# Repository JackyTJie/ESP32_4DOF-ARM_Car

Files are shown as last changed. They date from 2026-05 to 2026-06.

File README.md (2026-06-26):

# 第 16 届上海交通大学"黎明杯"新生机械创意大赛
> 主题：工道肇始，百卅同途 | 队名: Blitz
> 比赛结果：**十六强** **最佳设计奖**

<p align="center">
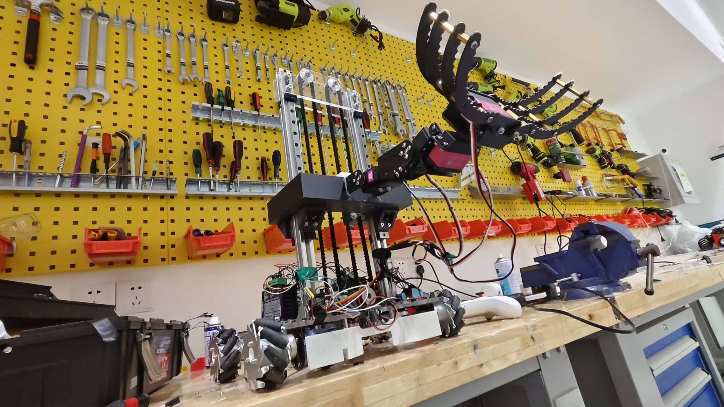
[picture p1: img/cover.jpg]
Cover
  <br/>
  <em>比赛用麦卡纳姆轮全向移动机器人总览</em>
</p>

<p align="center">
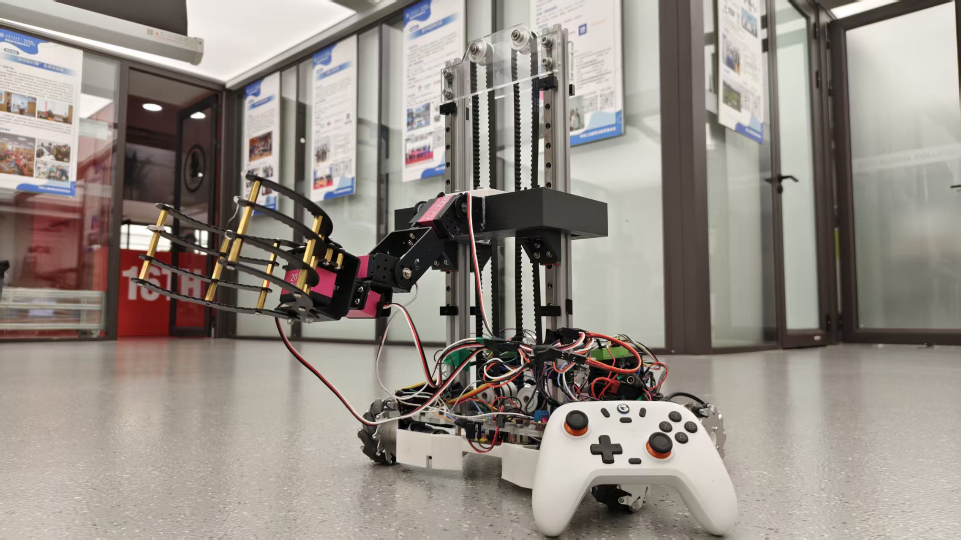
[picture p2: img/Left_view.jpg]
Left View
  
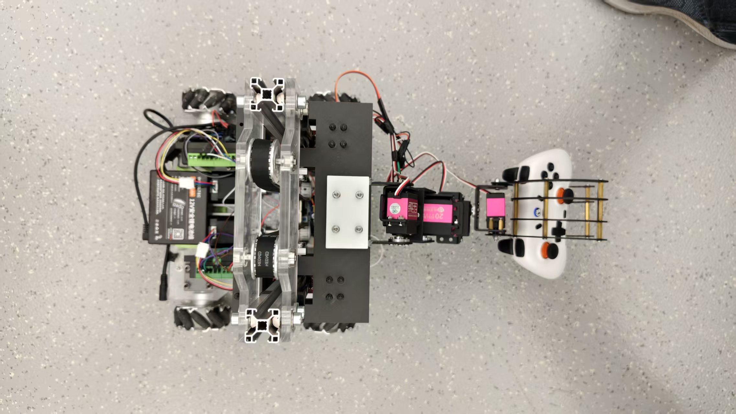
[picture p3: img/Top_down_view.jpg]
Top Down View
  <br/>
  <em>左视图 · 俯视图</em>
</p>

---

## 比赛信息

### 机器人规格限制 (Section 6.1)
| 参数 | 限制 | 当前状态 |
|---|---|---|
| 底盘尺寸 | ≤350×350mm | 符合 |
| 起始尺寸 | ≤450×450×650mm | 符合 |
| 最大展开 | ≤550×550×900mm | 符合 |
| 总重量 | ≤15kg | 符合 |
| 电池电压 | ≤13.2V | 符合(11.1V) |
| 行走电机 | ≤4 个 | 符合(4个MG513) |
| 任务电机 | 不限 | 已配置舵机+步进电机 |

---

## 项目概述
本项目是为第 16 届上海交通大学新生机械创意大赛设计的**麦卡纳姆轮全向移动机器人**。
已完成**Xbox蓝牙手柄控制、MPU6050智能坡道自动驻车、4路舵机机械臂控制、步进电机升降、电池低压保护、编码器速度滤波**全套核心功能，完全满足初赛/决赛关卡需求。

### 比赛关卡与功能完成度
| 关卡 | 任务描述 | 所需机构 | 完成状态 |
|---|---|---|---|
| 1. 奠基之路 | 搬运泡沫块填坑并上坡 | 底盘/推铲/坡道驻车 | **已完成** |
| 2. 权衡定鼎 | 搬运物块到300mm高台 | 机械臂/升降 |**已完成** |
| 3. 重枢巧径 | 操纵配重系统 | 挂钩/推杆 | **已完成** |
| 4. 参数扰行 | 从墙面取障碍物并布置 | 机械臂/夹爪 | **已完成** |
| 5. 同途归一 | 收集拼图并嵌入拼图板 | 机械臂/精密夹爪 | **已完成** |

### 核心功能
-  麦卡纳姆轮全向移动（前后/平移/旋转/混合）
-  **MPU6050六轴传感器·智能坡道自动驻车**（倾角>12°+摇杆回中自动锁轮）
-  Xbox Series X/S 蓝牙无线控制
-  4路舵机精准控制+一键复位
-  步进电机升降加减速控制
-  电池低压告警+临界电压强制停机
-  编码器速度采集+三阶滑动滤波
-  非线性速度曲线，操控更细腻

---

## 项目结构
```
Competition/
├── README.md                     # 主说明文档
├── Main_Control/                 # 主控制器（Xbox手柄·正式版）
│   ├── src/main.cpp              # 完整版主控（麦轮+驻车+舵机+升降）
│   └── Readme.md                 # 子模块文档
└── Robotics/                     # 机械结构设计
```

---

## 控制系统架构

### Main_Control - 底盘+机械臂一体化控制（最终正式版）
**硬件**：ESP32-S3-DevKitC-1 + I2C电机驱动(0x26) + I2C舵机驱动(0x2D) + MPU6050

#### 控制映射（与最新代码完全同步）
| 手柄输入 | 机器人动作 |
|---|---|
| 左摇杆↑↓ | 底盘前后移动 |
| 左摇杆←→ | 底盘左右平移 |
| 右摇杆←→ | 底盘原地旋转 |
| 右摇杆↑↓ | 升降平台控制 |
| Share/Start/Select | 舵机一键复位（3组预设） |
| A/B | 舵机4（夹爪）开关 |
| X/Y | 舵机3（臂身）调节 |
| 十字键 | 舵机1/2（基座/大臂）调节 |
| RT/RB | 机械臂纵深协调控制 |

#### 核心参数（最新校准版）
```cpp
PWM_MAX = 3600        // 最大输出
PWM_MIN = 50          // 最小启动
PWM_DEADZONE = 2000   // 摇杆死区
SLOPE_COMPENSATION_STEPS = 350  // 坡道驻车力度
SPEED_CURVE_EXP = 1.5  // 速度曲线指数
ANGLE_THRESHOLD = 12.0° // 驻车触发倾角
```

---

## 团队分工 (4人组)
| 角色 | 负责人 | 主要职责 | 当前状态 |
|---|---|---|---|
| **队长/机械设计组长** | xkt | 机械臂设计、底盘装配、结构优化 | 完成 |
| **电控组长** | tj | 系统架构、主控代码、调试集成 | **完成** |
| **嵌入式软件** | xjs | 传感器调试、舵机/步进电机控制、联调 | **完成** |
| **策略与测试** | fzx | 比赛策略、场地测试、文档管理 |  **完成** |

---

## 快速开始
### 环境搭建
1. 安装 VSCode + PlatformIO 插件
2. 打开 `Main_Control` 项目
3. 核对手柄MAC地址：`#define XBOX_MAC "2d:89:6d:41:41:6a"`
4. 编译上传：
```bash
pio run --target upload
pio device monitor
```

---

## 致谢

本项目参考了以下开源项目，在此表示衷心感谢：

| 项目 | 用途 |
|---|---|
| [LiZhiY0u/ESP32_connect_XboxController](https://github.com/LiZhiY0u/ESP32_connect_XboxController) | Xbox 手柄 ESP32 蓝牙连接参考 |
| [asukiaaa/arduino-XboxSeriesXControllerESP32](https://github.com/asukiaaa/arduino-XboxSeriesXControllerESP32) | Xbox Series X/S 控制器 ESP32 驱动库 |
| [asukiaaa/arduino-XboxSeriesXHIDReportBuilder](https://github.com/asukiaaa/arduino-XboxSeriesXHIDReportBuilder) | Xbox Series X HID 报告构建器 |
| [asukiaaa/arduino-XboxControllerNotificationParser](https://github.com/asukiaaa/arduino-XboxControllerNotificationParser) | Xbox 控制器通知解析器 |
| [A-lexisL/esp32_car](https://github.com/A-lexisL/esp32_car) | 提供部分灵感 |

感谢所有开源社区贡献者的无私分享！

---

**最后更新**: 2026-06-26

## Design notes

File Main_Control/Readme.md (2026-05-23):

# Main_Control — ESP32-S3 Robot Control System

An integrated robot control system for the **16th SJTU Freshman Mechanical Creativity Competition**, built on ESP32-S3 with an Xbox wireless controller. Features mecanum omnidirectional drive, servo arm control, stepper lift, MPU6050 slope parking, and battery protection.

> **Competition result:** Qualified for finals (13th in preliminaries)

## Hardware Overview

| Component | Model / Spec | Role |
|---|---|---|
| **MCU** | ESP32-S3-DevKitC-1 | Main controller, Bluetooth & I2C |
| **Remote** | Xbox Series X/S (BLE) | Wireless control input |
| **Motor driver** | I2C PWM driver (addr `0x26`) | 4-ch DC motor control |
| **Drive motors** | MG513 geared DC ×4 | Mecanum wheel actuation |
| **Servos** | Standard SG90-style ×4 | Arm / gripper mechanism |
| **Stepper** | 2-phase hybrid ×2 | Lift /升降 mechanism |
| **IMU** | MPU6050 | Tilt detection for auto-parking |
| **Relay** | 5V 1-ch | System power reset |

## Pin Connection Guide

### I2C Bus (Motor Driver & MPU6050)

| ESP32-S3 | Device | Wire |
|---|---|---|
| GPIO 8 (SDA) | Motor driver SDA, MPU6050 SDA | Data |
| GPIO 9 (SCL) | Motor driver SCL, MPU6050 SCL | Clock |

The I2C bus runs at 100 kHz. Both the motor driver (addr `0x26`) and MPU6050 share the same bus.

### Servo PWM (LEDC, 50 Hz, 14-bit)

| ESP32-S3 | Servo | Signal range |
|---|---|---|
| GPIO 4 | Servo 1 | 0–180° (500–2500 µs) |
| GPIO 5 | Servo 2 | 0–180° |
| GPIO 6 | Servo 3 | 0–180° |
| GPIO 7 | Servo 4 | 0–180° |

### Stepper Motors (Shared Step/Dir)

| ESP32-S3 | Stepper 1 | Stepper 2 |
|---|---|---|
| GPIO 15 | STEP | — |
| GPIO 16 | DIR | — |
| GPIO 17 | SLEEP | — |
| GPIO 18 | — | STEP |
| GPIO 19 | — | DIR |
| GPIO 20 | — | SLEEP |

Both steppers share the same step pulse and direction signals — they move in sync. SLEEP pins are pulled HIGH on init to enable the drivers.

### Relay

| ESP32-S3 | Relay |
|---|---|
| GPIO 12 | Signal (active HIGH, normally ON) |

The relay is ON by default. Pressing the Xbox **Home** button triggers a 5-second OFF cycle to reset the system power.

## Code Architecture

The firmware is structured as modular C++ classes, each responsible for one hardware subsystem:

```
main.cpp
├── MotorDriver      — I2C 4-ch PWM (forward/back + speed)
├── ServoController  — LEDC servo PWM with non-blocking homing
├── MPUManager       — MPU6050 tilt read (single-init guard)
├── StepperDriver    — Shared step/dir with acceleration ramp
├── BatteryMonitor   — Voltage polling (2 s interval)
├── XboxInput        — Joystick → speed curve + mutual exclusion
├── ChassisController— Mecanum kinematics + auto-parking
├── RelayControl     — Power reset (non-blocking)
└── ServoButtonHandler— Button-to-servo mapping (40 ms throttle)
```

### Control Loop

```
loop() every 20 ms
├── xbox.update()           — poll BLE
├── relay.update()          — handle reset timer
├── xbox.process()          — stick → speed curve + filter
├── stepper.update()        — acceleration ramp
├── servoButtons.handle()   — button → servo angle (40 ms)
├── servo.heartbeat()       — re-send angle every 800 ms
├── [20 ms throttle]
│   ├── mpu.updateAndGetTilt()
│   ├── battery.update()
│   ├── chassis.compute()   — mecanum solve
│   └── motor.setPWM()
└── Serial debug (500 ms)
```

## Xbox Controller Mapping

### Chassis (Mecanum Drive)

| Stick | Action |
|---|---|
| Left stick ↑↓ | Forward / backward |
| Left stick ←→ | Strafe left / right |
| Right stick ←→ | Rotate in place |

### Lift (Stepper Motor)

| Stick | Action |
|---|---|
| Right stick ↑↓ | Lift up / down |

Right stick is **mutually exclusive** — when X displacement dominates, rotation is active; when Y dominates, lift is active.

### Servo Arm

| Button | Servo 1 | Servo 2 | Servo 3 | Servo 4 |
|---|---|---|---|---|
| RT | +2° | −2° | — | — |
| RB | −2° | +2° | — | — |
| D-pad ← / → | +2° / −2° | — | — | — |
| D-pad ↑ / ↓ | — | −2° / +2° | — | — |
| X / Y | — | — | +2° / −2° | — |
| A / B | — | — | — | +2° / −2° |

### One-Click Presets

| Button | Servo angles [1, 2, 3, 4] |
|---|---|
| Share | 50°, 120°, 50°, 130° |
| Start | 116°, 53°, 50°, 130° |
| Select | 74°, 145°, 48°, 130° |

### Other

| Button | Action |
|---|---|
| Home | Trigger relay reset (5 s power cycle) |

## Key Features

### Mecanum Kinematics

Standard mecanum-wheel forward kinematics with automatic normalization:

```
FL =  Y + X + R
FR =  Y − X − R
BL =  Y − X + R
BR =  Y + X − R
```

Values exceeding ±1000 are normalized to prevent saturation.

### Slope Auto-Parking

When all joysticks are centered (deadband < 30) and MPU6050 detects a tilt > 12°, the controller applies a holding torque to prevent rollback on slopes.

### Stepper Acceleration Ramp

Step interval ramps smoothly between target speed and current speed (100 µs steps, 20 ms update rate) to avoid mechanical shock.

### Battery Protection

| Voltage | Behavior |
|---|---|
| > 6.0 V | Normal |
| 5.5–6.0 V | Warning (displayed in serial) |
| < 5.5 V | Motor output disabled |

## Build & Flash

This project uses **PlatformIO**.

1. Clone the repo:
   ```bash
   git clone https://github.com/your-org/Main_Control.git
   cd Main_Control
   ```
2. Configure your Xbox MAC address in `src/main.cpp`:
   ```cpp
   #define XBOX_MAC "xx:xx:xx:xx:xx:xx"
   ```
3. Build and upload:
   ```bash
   pio run -t upload
   ```
4. Monitor serial output:
   ```bash
   pio device monitor -b 115200
   ```

## Dependencies (platformio.ini)

- NimBLE-Arduino @ 1.4.2
- Adafruit MPU6050 @ 2.2.9
- Adafruit Unified Sensor @ 1.1.15

## Serial Debug Output

Every 500 ms the system prints one line:

```
Mode:0 Park:0 Tilt:0.0 V:7.4 | Joy:0,0 Rot:0 Lift:0 | Servo:110,45,50,110 | Relay:1
```

Fields: operating mode, parking status, tilt angle (°), battery voltage (V), joystick/rotation/lift values, servo angles, relay state.

## License

MIT — feel free to use and modify for your own competition or robotics project.

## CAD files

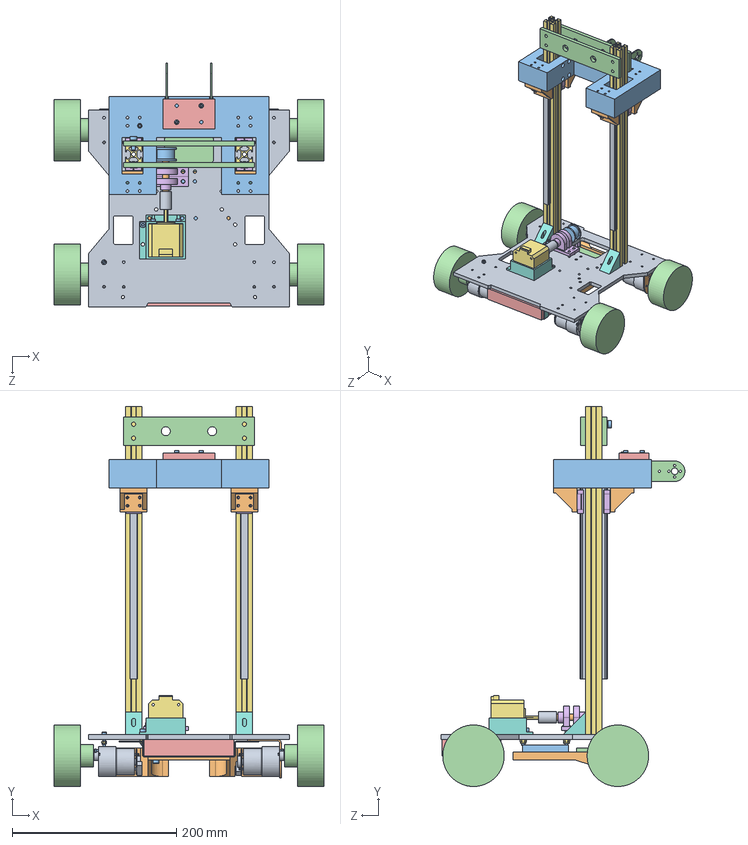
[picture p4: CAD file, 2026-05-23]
Robotics/General.SLDASM
329.0 x 463.2 x 297.2 mm
Wheel motor x 4
Cap Head Hexagon Screws-SJTU x 17
Mecanum_new x 4
Plain Washers-SJTU x 6
Al Hex Pillar_Double Internal Thread-SJTU
Nylon Hexagon Nuts-SJTU x 4
Holder
Floor
Sheld_revision
Motor Controller
Power Supply
Powertrain
MTN9C x 4
Extrusions x 2
Corner Bracket x 2
Guide Line x 4
Corner Bracket_abs x 4
Platform_new
Support
Clamping Plate
KP08 x 2
Stepper Motor
Base_l
Coupling
Shaft
Synchronous Pulley
Plate x 2

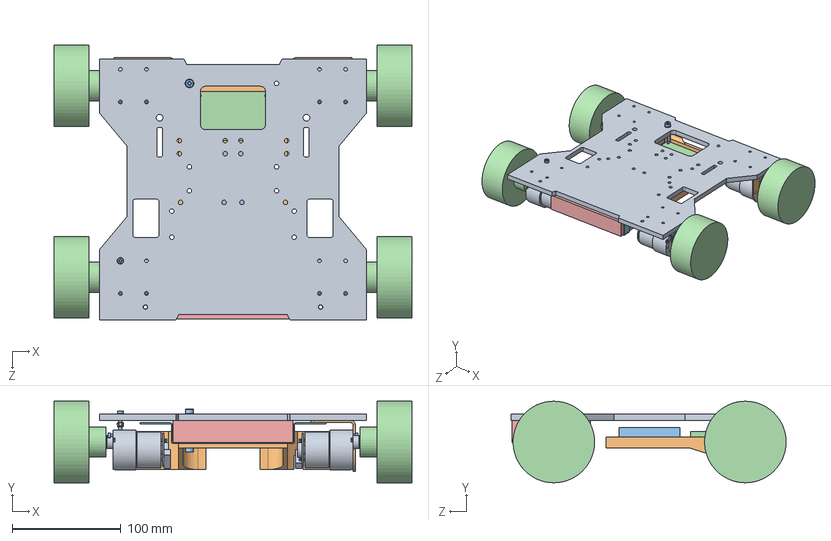
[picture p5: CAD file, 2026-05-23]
Robotics/Floor/General_Floor.SLDASM
329.0 x 75.0 x 253.0 mm
Wheel motor x 4
Cap Head Hexagon Screws-SJTU x 7
Mecanum_new x 4
Plain Washers-SJTU x 2
Al Hex Pillar_Double Internal Thread-SJTU
Nylon Hexagon Nuts-SJTU
Holder
Floor
Sheld_revision
Motor Controller
Power Supply
Powertrain

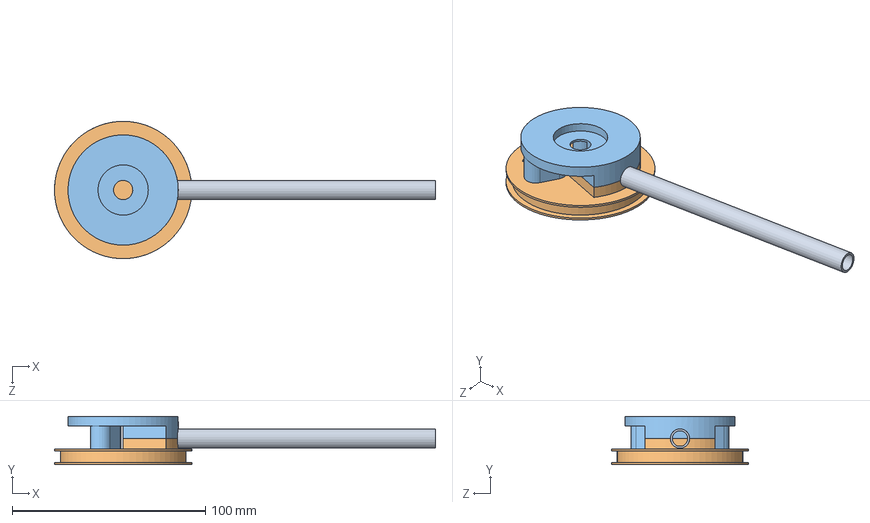
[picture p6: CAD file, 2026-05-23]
Robotics/Arm/Connecting Rod.SLDASM
197.0 x 25.0 x 71.0 mm
Al Pipe
Base
Middle

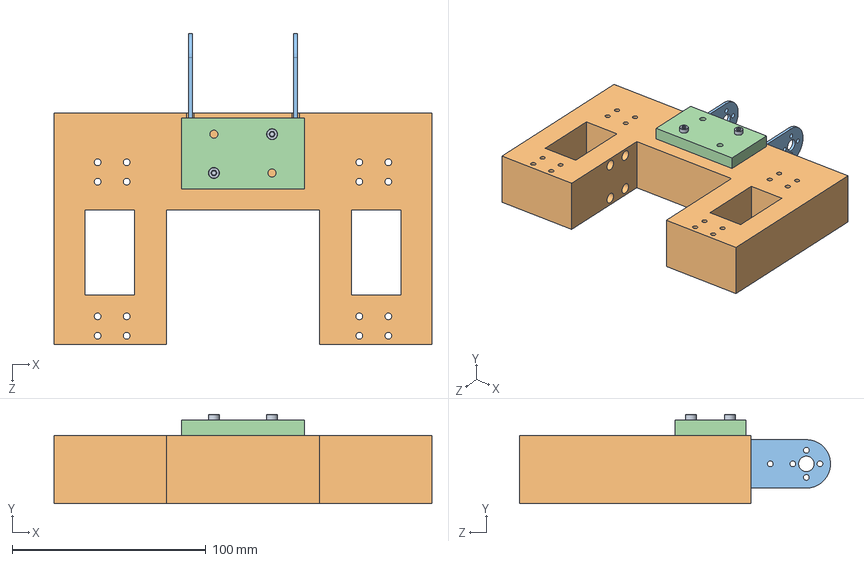
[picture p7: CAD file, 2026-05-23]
Robotics/Arm/Platform_new.SLDASM
195.0 x 46.0 x 160.4 mm
Cap Head Hexagon Screws-SJTU x 2
Platform_new
Support
Clamping Plate

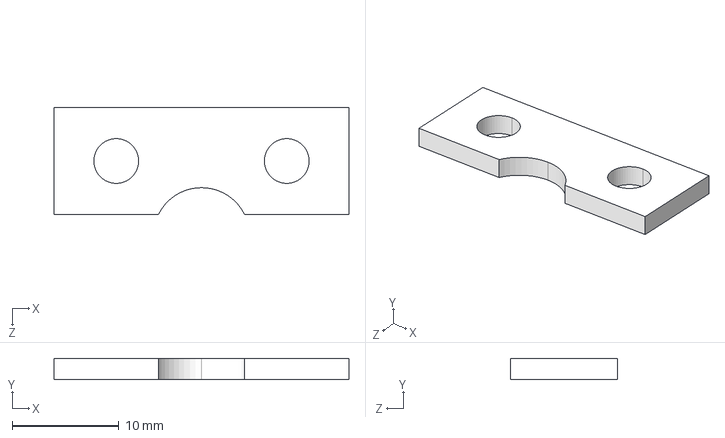
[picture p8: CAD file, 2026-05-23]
Robotics/Arm/Positioning Plate_front.STEP
27.7 x 2.00 x 10.0 mm

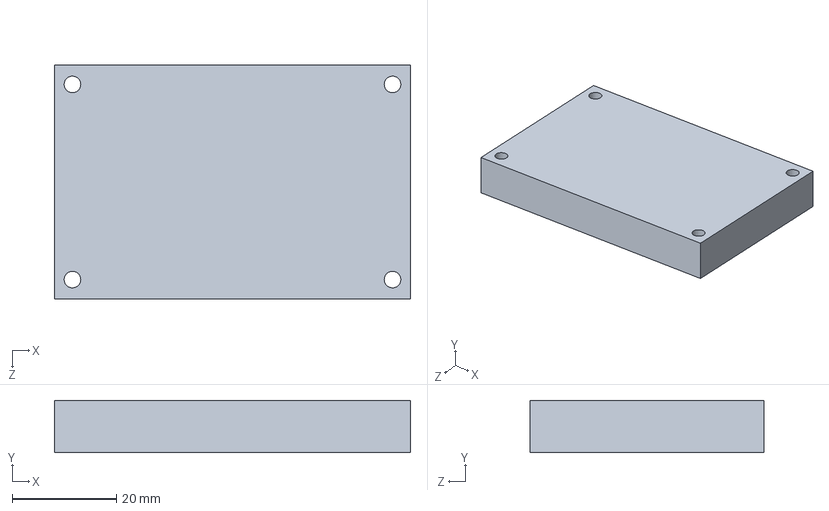
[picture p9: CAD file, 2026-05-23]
Robotics/Controller Module/Power Supply.SLDPRT
68.4 x 10.0 x 44.9 mm

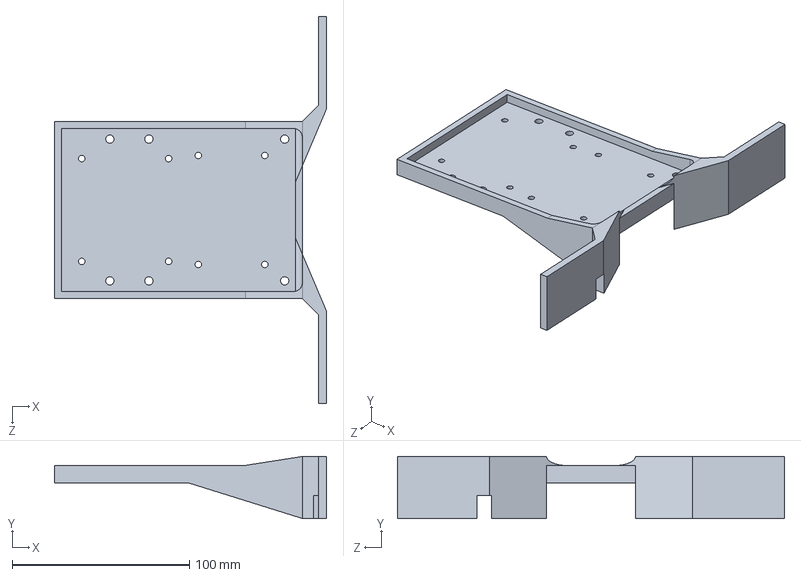
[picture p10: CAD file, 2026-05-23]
Robotics/Floor/Sheld_revision.SLDPRT
153.7 x 35.0 x 218.4 mm

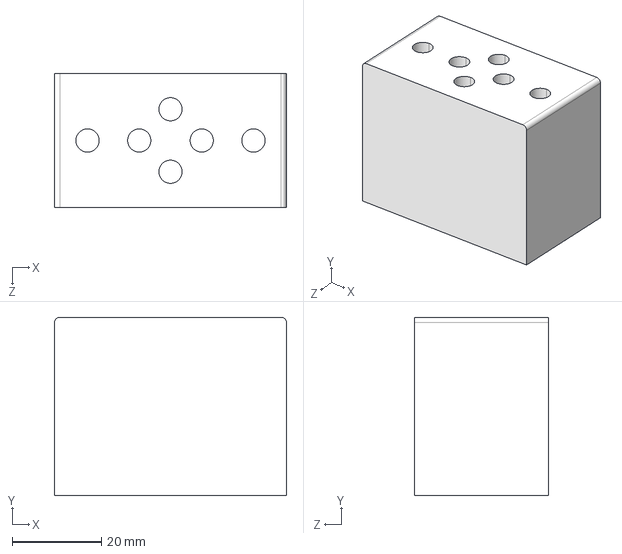
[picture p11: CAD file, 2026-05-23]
Robotics/Arm/Connect.STEP
52.0 x 40.0 x 30.0 mm

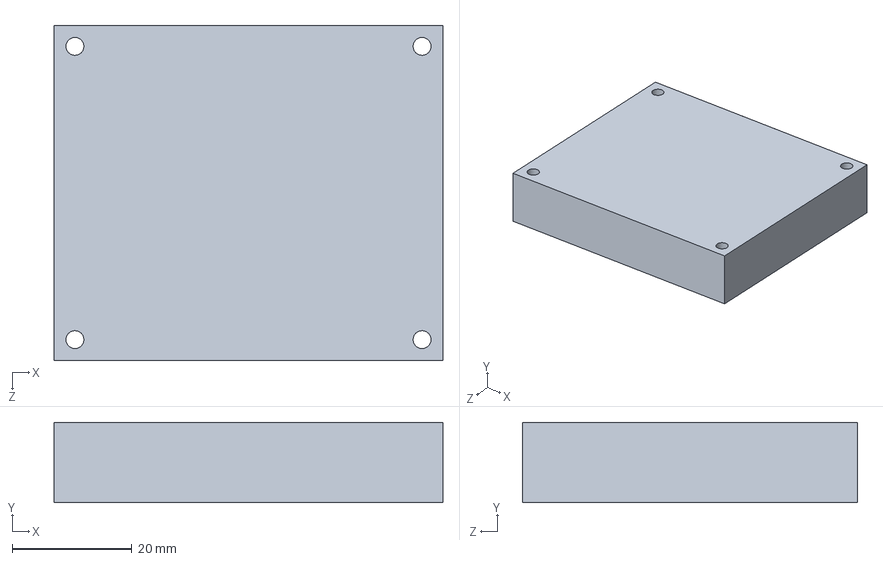
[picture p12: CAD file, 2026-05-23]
Robotics/Controller Module/Motor Controller.SLDPRT
65.0 x 13.4 x 56.0 mm

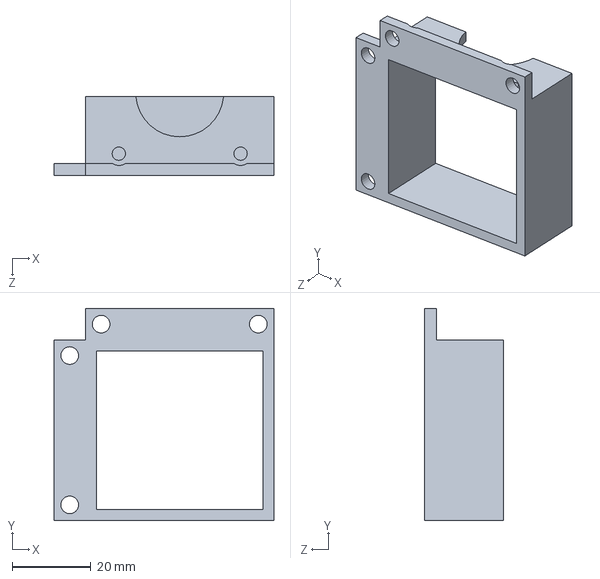
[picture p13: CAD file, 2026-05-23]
Robotics/Floor/Base_r.SLDPRT
56.0 x 54.0 x 20.0 mm

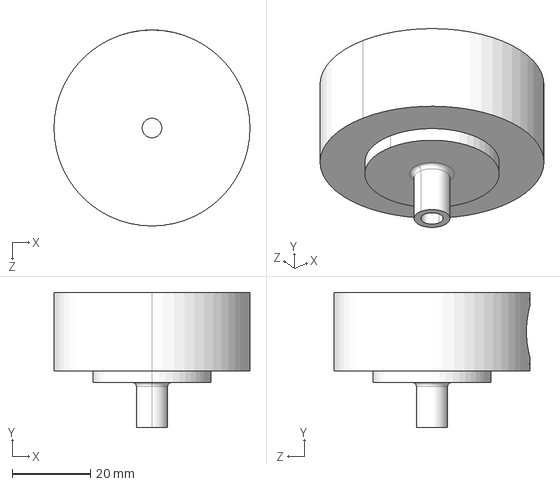
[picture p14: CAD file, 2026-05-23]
Robotics/Arm/Pan-tilt.STEP
50.0 x 34.5 x 50.0 mm

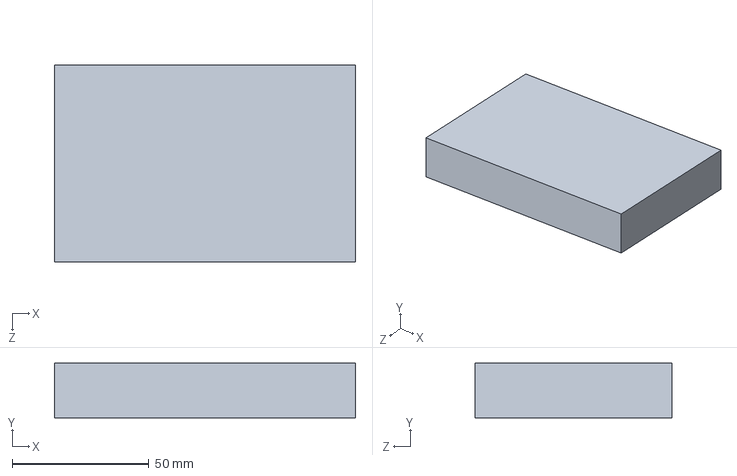
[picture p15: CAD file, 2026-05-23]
Robotics/Controller Module/Powertrain.SLDPRT
110.0 x 20.0 x 72.0 mm

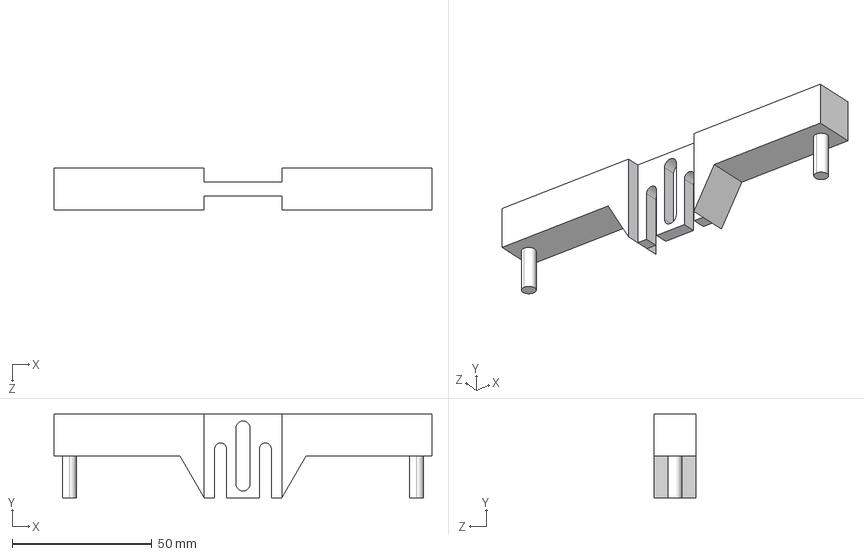
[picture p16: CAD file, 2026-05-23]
Robotics/Arm/Bridge_front.STEP
135.0 x 30.0 x 15.0 mm

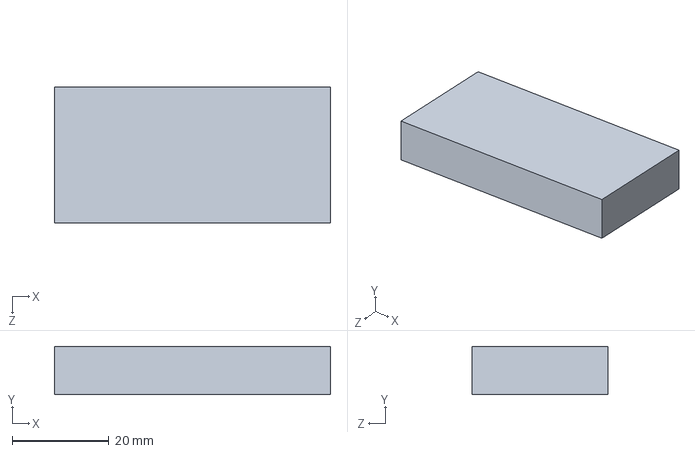
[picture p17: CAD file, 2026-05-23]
Robotics/Controller Module/ESP32.SLDPRT
57.0 x 10.0 x 28.0 mm

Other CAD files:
Robotics/Floor/Holder.SLDPRT
Robotics/Floor/Baffle.SLDPRT
Robotics/Arm/Clamping Plate.SLDPRT
Robotics/Arm/Base.SLDPRT
Robotics/Arm/Bridge.SLDPRT
Robotics/Arm/Bridge_rear.STEP
Robotics/Arm/Connect.SLDPRT
Robotics/Arm/Connecter.SLDPRT
Robotics/Arm/Cover.SLDPRT
Robotics/Arm/Director.SLDPRT
Robotics/Arm/Middle.SLDPRT
Robotics/Arm/Neck.SLDPRT
Robotics/Arm/Pan-tilt.SLDASM
Robotics/Arm/Pan-tilt.SLDPRT
Robotics/Arm/Plate.SLDPRT
Robotics/Arm/Platform.SLDASM
Robotics/Arm/Platform.SLDPRT
Robotics/Arm/Platform.STEP
Robotics/Arm/Platform_new.SLDPRT
Robotics/Arm/Positioning Plate_front.SLDPRT
Robotics/Arm/Positioning Plate_rear.SLDPRT
Robotics/Arm/Positioning Plate_rear.STEP
Robotics/Arm/Pressing Plate.SLDPRT
Robotics/Arm/Side.SLDPRT
Robotics/Floor/Base_l.SLDPRT
Robotics/Floor/Floor.DWG
Robotics/Floor/Floor.DXF
Robotics/Floor/Floor.SLDPRT
Robotics/Floor/MirrorBaffle.SLDPRT
Robotics/Floor/Sheld.SLDASM
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

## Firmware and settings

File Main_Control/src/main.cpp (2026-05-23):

// Copyright 2026 Blitz Team
#include <Arduino.h>
#include <Wire.h>
#include <Adafruit_MPU6050.h>
#include <Adafruit_Sensor.h>
#include <algorithm>
#include <cmath>
#include <cstdint>
#include "XboxSeriesXControllerESP32_asukiaaa.hpp"

// ============================================================================
// Pin & hardware configuration
// ============================================================================
#define XBOX_MAC "2d:89:6d:41:41:6a"
#define I2C_SDA 8
#define I2C_SCL 9
#define MOTOR_ADDR 0x26

// Servo PWM pins
#define SERVO1_PIN 4
#define SERVO2_PIN 5
#define SERVO3_PIN 6
#define SERVO4_PIN 7

// Relay pin
#define RELAY_PIN 12

// Stepper motor pins
const int STEP2_PIN = 15;
const int DIR2_PIN = 16;
const int SLEEP2_PIN = 17;
const int STEP3_PIN = 18;
const int DIR3_PIN = 19;
const int SLEEP3_PIN = 20;

// ============================================================================
// Motor driver — I2C-controlled 4-channel PWM
// ============================================================================
class MotorDriver {
public:
    void begin(TwoWire &wire = Wire, uint8_t addr = MOTOR_ADDR) {
        _wire = &wire;
        _addr = addr;
    }

    void setPWM(const int16_t (&pwm)[4]) {
        _wire->beginTransmission(_addr);
        _wire->write(0x07); // REG_PWM
        for (int i = 0; i < 4; i++) {
            int16_t val = constrain(pwm[i], -3600, 3600);
            _wire->write(val >> 8);
            _wire->write(val & 0xFF);
        }
        _wire->endTransmission();
    }

    void stop() {
        int16_t zero[4] = {0};
        setPWM(zero);
    }

    float readVoltage() {
        _wire->beginTransmission(_addr);
        _wire->write(0x08); // REG_VOLT
        _wire->endTransmission(false);
        if (_wire->requestFrom(_addr, (uint8_t)2) == 2) {
            uint16_t raw = (_wire->read() << 8) | _wire->read();
            return raw / 10.0f;
        }
        return -1.0f; // read failed
    }

private:
    TwoWire *_wire;
    uint8_t _addr;
};

// ============================================================================
// Servo controller — non-blocking PWM via LEDC
// ============================================================================
class ServoController {
public:
    void begin() {
        const uint8_t pins[4] = {SERVO1_PIN, SERVO2_PIN, SERVO3_PIN, SERVO4_PIN};
        for (int i = 0; i < 4 ; i++) {
            ledcSetup(i, 50, 14);          // 50Hz, 14-bit
            ledcAttachPin(pins[i], i);
        }
        // Send initial angles
        uint8_t defaults[4] = {110, 45, 50, 110};
        homeAsync(defaults);
        // Wait for homing to finish (one-time init)
        uint32_t start = millis();
        while (!_homingComplete && millis() - start < 2000) {
            update(millis());
        }
    }

    void setAngle(uint8_t index, uint8_t angle) {
        if (index >= 4) return;
        angle = constrain(angle, 0, 180);
        uint32_t duty = map(angle, 0, 180, _dutyMin, _dutyMax);
        ledcWrite(index, duty);
    }

    // Re-send angles periodically to maintain position
    void heartbeat(uint32_t nowMs) {
        if (!_homingComplete) return;
        if (nowMs - _lastHeartbeat > 800) {
            _lastHeartbeat = nowMs;
            for (int i = 0; i < 4; i++) setAngle(i, _angles[i]);
        }
    }

    // Start homing sequence (applies angles one by one)
    void homeAsync(const uint8_t (&angles)[4]) {
        for (int i = 0; i < 4; i++) _angles[i] = angles[i];
        _homingIndex = 3;  // start from the last servo
        _homingComplete = false;
        _lastHomingStep = 0;
    }

    // Call frequently; steps through servos at 300ms intervals
    void update(uint32_t nowMs) {
        if (_homingComplete) return;
        if (nowMs - _lastHomingStep >= 300) {
            setAngle(_homingIndex, _angles[_homingIndex]);
            _homingIndex--;
            _lastHomingStep = nowMs;
            if (_homingIndex < 0) _homingComplete = true;
        }
    }

    bool isHoming() const { return !_homingComplete; }
    uint8_t &angle(uint8_t idx) { return _angles[idx]; }
    const uint8_t &angle(uint8_t idx) const { return _angles[idx]; }

private:
    uint8_t _angles[4] = {110, 45, 50, 110};
    bool _homingComplete = true;
    int8_t _homingIndex = 0;
    uint32_t _lastHomingStep = 0;
    uint32_t _lastHeartbeat = 0;
    static const uint32_t _dutyMin = (500 * (1<<14)) / 20000;
    static const uint32_t _dutyMax = (2500 * (1<<14)) / 20000;
};

// ============================================================================
// MPU6050 tilt sensor — single-init guard
// ============================================================================
class MPUManager {
public:
    bool begin() {
        _initialized = mpu.begin();
        if (_initialized) {
            mpu.setAccelerometerRange(MPU6050_RANGE_8_G);
            mpu.setGyroRange(MPU6050_RANGE_500_DEG);
        }
        return _initialized;
    }

    bool isInitialized() const { return _initialized; }

    float updateAndGetTilt() {
        if (!_initialized) return 0;
        sensors_event_t a, g, t;
        mpu.getEvent(&a, &g, &t);
        accelX = a.acceleration.x;
        accelY = a.acceleration.y;
        accelZ = a.acceleration.z;
        // Returns tilt angle (degrees) from XZ plane
        return atan2(fabs(accelX), fabs(accelZ)) * 180.0 / PI;
    }

    // Combined pitch/roll for debugging
    float getDebugAngle() const {
        float pitch = atan2(accelX, sqrt(accelY*accelY + accelZ*accelZ)) * 180.0 / PI;
        float roll = atan2(-accelY, accelZ) * 180.0 / PI;
        return std::max(fabs(pitch), fabs(roll));
    }

    float accelX = 0, accelY = 0, accelZ = 0;
private:
    Adafruit_MPU6050 mpu;
    bool _initialized = false;
};

// ============================================================================
// Stepper motor driver — shared step/dir for two motors
// ============================================================================
class StepperDriver {
public:
    void begin() {
        pinMode(STEP2_PIN, OUTPUT); pinMode(DIR2_PIN, OUTPUT); pinMode(SLEEP2_PIN, OUTPUT);
        pinMode(STEP3_PIN, OUTPUT); pinMode(DIR3_PIN, OUTPUT); pinMode(SLEEP3_PIN, OUTPUT);
        digitalWrite(SLEEP2_PIN, HIGH);
        digitalWrite(SLEEP3_PIN, HIGH);
    }

    void setSpeed(int16_t speed) {
        _targetSpeed = speed;
    }

    // Call frequently; handles acceleration ramping
    void update() {
        if (_targetSpeed == 0) {
            _currentInterval = M2_MIN_DELAY;
            return;
        }
        uint32_t now = micros();
        digitalWrite(DIR2_PIN, _targetSpeed < 0 ? HIGH : LOW);
        digitalWrite(DIR3_PIN, _targetSpeed < 0 ? LOW : HIGH);
        int targetInterval = map(abs(_targetSpeed), 0, 1000, M2_MIN_DELAY, M2_MAX_DELAY);
        if (millis() - _lastAccel >= 20) {
            if (_currentInterval > targetInterval)
                _currentInterval = std::max(_currentInterval - M2_ACCEL_STEP, (float)targetInterval);
            else if (_currentInterval < targetInterval)
                _currentInterval = std::min(_currentInterval + M2_ACCEL_STEP, (float)targetInterval);
            _lastAccel = millis();
        }
        if (now - _lastStep >= (uint32_t)_currentInterval) {
            digitalWrite(STEP2_PIN, !digitalRead(STEP2_PIN));
            digitalWrite(STEP3_PIN, !digitalRead(STEP3_PIN));
            _lastStep = now;
        }
    }

    void stop() { setSpeed(0); }

private:
    int16_t _targetSpeed = 0;
    float _currentInterval = M2_MIN_DELAY;
    uint32_t _lastStep = 0, _lastAccel = 0;
    static const int M2_MIN_DELAY = 1500;
    static const int M2_MAX_DELAY = 700;
    static const int M2_ACCEL_STEP = 100;
};

// ============================================================================
// Battery monitoring
// ============================================================================
class BatteryMonitor {
public:
    enum Status { BAT_OK, BAT_LOW, BAT_CRITICAL };
    void update(MotorDriver &motor) {
        if (millis() - _lastCheck < 2000) return;
        _lastCheck = millis();
        float v = motor.readVoltage();
        if (v < 0) return;
        if (v < 5.5) status = BAT_CRITICAL;
        else if (v < 6.0) status = BAT_LOW;
        else status = BAT_OK;
        voltage = v;
    }
    Status status = BAT_OK;
    float voltage = 0;
private:
    uint32_t _lastCheck = 0;
};

// ============================================================================
// Xbox controller input — stick mapping & mutual exclusion preserved
// ============================================================================
class XboxInput {
public:
    void begin() { xbox.begin(); }
    void update() { xbox.onLoop(); connected = xbox.isConnected(); }
    bool isConnected() const { return connected; }

    // Left stick: x = forward/back, y = strafe (matches original ctrl_x/ctrl_y)
    void getLeftStick(int16_t &x, int16_t &y) const {
        x = _lxFiltered;
        y = _lyFiltered;
    }
    // Rotation (right stick X, filtered)
    int16_t getRotation() const { return _rxFiltered; }
    // Lift (right stick Y, unfiltered direct speed-curve result)
    int16_t getLift() const { return _ryValue; }

    bool isLiftActive() const { return _ryValue != 0; }
    bool isRotateActive() const { return _rxDominant; }

    XboxSeriesXControllerESP32_asukiaaa::Core &raw() { return xbox; }

    void process() {
        if (!connected) return;

        // Left stick processing
        int16_t rawY = _processAxis(xbox.xboxNotif.joyLVert);   // forward/back
        int16_t rawX = -_processAxis(xbox.xboxNotif.joyLHori);  // strafe (inverted)
        int16_t curveY = _speedCurve(rawY) * LINEAR_SENSITIVITY;
        int16_t curveX = _speedCurve(rawX) * STRAFE_SENSITIVITY;

        // ctrl_x = -ly, ctrl_y = -lx (preserves original mapping)
        _lxFiltered = _lowPass(_lxFiltered, -curveY, CTRL_ALPHA);
        _lyFiltered = _lowPass(_lyFiltered, -curveX, CTRL_ALPHA);

        // Right stick mutual exclusion (replicates original processRightJoystick exactly)
        int16_t processedRX = _processAxis(xbox.xboxNotif.joyRHori);
        int16_t processedRY = _processAxis(xbox.xboxNotif.joyRVert);
        int16_t absRX = abs(processedRX);
        int16_t absRY = abs(processedRY);

        _rxDominant = false;
        if (absRX > RIGHT_DEADZONE || absRY > RIGHT_DEADZONE) {
            if (absRX > absRY * 1.2) {
                _rxDominant = true;
                _ryValue = 0;
            } else if (absRY > absRX * 1.2) {
                _ryValue = processedRY;
                _rxDominant = false;
            } else {
                _rxDominant = true;
                _ryValue = 0;
            }
        } else {
            _ryValue = 0;
        }

        // Apply speed curve & filter to rotation value
        int16_t rxForRotate = _rxDominant ? processedRX : 0;
        rxForRotate = _speedCurve(rxForRotate);
        _rxFiltered = _lowPass(_rxFiltered, -rxForRotate * RX_SENSITIVITY, RX_ALPHA);

        // Lift value: speed curve only (no filter, no sensitivity scaling)
        if (_ryValue != 0) {
            _ryValue = _speedCurve(_ryValue);
        }
    }

private:
    int16_t _processAxis(uint16_t raw) {
        if (raw > 32767 - DEADZONE && raw < 32767 + DEADZONE) return 0;
        if (raw < 32767) return -map(raw, 0, 32767 - DEADZONE, 1000, 0);
        else return map(raw, 32767 + DEADZONE, 65535, 0, 1000);
    }
    int16_t _speedCurve(int16_t v) {
        if (v == 0) return 0;
        int16_t sign = (v > 0) ? 1 : -1;
        float norm = abs(v) / 1000.0f;
        float curved = pow(norm, CURVE_EXP);
        int16_t out = round(curved * 1000);
        if (out > 0 && out < 3) out = 3;
        return sign * out;
    }
    float _lowPass(float prev, float input, float alpha) {
        return prev * (1.0f - alpha) + input * alpha;
    }

    XboxSeriesXControllerESP32_asukiaaa::Core xbox{XBOX_MAC};
    bool connected = false;
    float _lxFiltered = 0, _lyFiltered = 0;
    float _rxFiltered = 0;
    int16_t _ryValue = 0;
    bool _rxDominant = false;

    static const int16_t DEADZONE = 600;        // joystick deadzone
    static const int16_t RIGHT_DEADZONE = 20;   // right stick deadzone
    static constexpr float CURVE_EXP = 4.0f;
    static constexpr float LINEAR_SENSITIVITY = 0.6f;
    static constexpr float STRAFE_SENSITIVITY = 0.6f;
    static constexpr float CTRL_ALPHA = 0.20f;
    static constexpr float RX_SENSITIVITY = 0.25f;
    static constexpr float RX_ALPHA = 0.25f;
};

// ============================================================================
// Mecanum kinematics & slope parking
// ============================================================================
class ChassisController {
public:
    enum Mode { IDLE, STRAIGHT, STRAFE, ROTATE, MIXED, PARKING };

    void compute(int16_t y, int16_t x, int16_t rot, bool forcePark) {
        _mode = IDLE;
        if (forcePark) {
            _mode = PARKING;
            _pwm[0] =  300; _pwm[1] = -300;
            _pwm[2] = -300; _pwm[3] =  300;
            return;
        }

        if (rot != 0 && x == 0 && y == 0) _mode = ROTATE;
        else if (y != 0 && x == 0 && rot == 0) _mode = STRAIGHT;
        else if (x != 0 && y == 0 && rot == 0) _mode = STRAFE;
        else if (x != 0 || y != 0 || rot != 0) _mode = MIXED;

        float fl = y + x + rot;
        float fr = y - x + rot;
        float bl = y - x - rot;
        float br = y + x - rot;
        float maxVal = std::max({fabs(fl), fabs(fr), fabs(bl), fabs(br)});
        if (maxVal > 1000.0f) {
            fl = fl / maxVal * 1000.0f;
            fr = fr / maxVal * 1000.0f;
            bl = bl / maxVal * 1000.0f;
            br = br / maxVal * 1000.0f;
        }
        auto toPWM = [](float v) {
            if (v == 0) return 0;
            int16_t sign = (v > 0) ? 1 : -1;
            int16_t absV = abs((int16_t)v);
            int16_t pwm = map(absV, 0, 1000, 0, 3600);
            if (pwm > 0 && pwm < 5) pwm = 5;
            return sign * pwm;
        };
        _pwm[0] = toPWM(fl); _pwm[1] = toPWM(fr);
        _pwm[2] = toPWM(bl); _pwm[3] = toPWM(br);
    }

    void getPWM(int16_t (&out)[4]) const {
        for (int i = 0; i < 4; i++) out[i] = _pwm[i];
    }
    Mode mode() const { return _mode; }

    static bool shouldPark(int16_t ly, int16_t lx, int16_t rx, int16_t ry, float tilt) {
        if (abs(ly) > 30 || abs(lx) > 30 || abs(rx) > 30 || abs(ry) > 30) return false;
        return tilt > 12.0f;
    }

private:
    int16_t _pwm[4] = {0};
    Mode _mode = IDLE;
};

// ============================================================================
// Relay control — non-blocking
// ============================================================================
class RelayControl {
public:
    void begin() { pinMode(RELAY_PIN, OUTPUT); set(true); }
    void set(bool on) { digitalWrite(RELAY_PIN, on ? HIGH : LOW); _state = on; }
    bool state() const { return _state; }
    void triggerReset() { _resetActive = true; _resetStart = millis(); set(false); }
    void update() {
        if (_resetActive && millis() - _resetStart >= 5000) {
            set(true);
            _resetActive = false;
        }
    }
    bool isResetting() const { return _resetActive; }
private:
    bool _state = true;
    bool _resetActive = false;
    uint32_t _resetStart = 0;
};

// ============================================================================
// Servo button handler — 40ms throttle
// ============================================================================
class ServoButtonHandler {
public:
    bool handle(XboxInput &xbox, ServoController &servo, uint32_t nowMs) {
        if (servo.isHoming()) return false;
        if (nowMs - _lastUpdate < 40) return false;
        _lastUpdate = nowMs;

        bool update = false;
        uint8_t &s0 = servo.angle(0), &s1 = servo.angle(1);
        uint8_t &s2 = servo.angle(2), &s3 = servo.angle(3);

        if (xbox.raw().xboxNotif.btnShare) { servo.homeAsync({50, 120, 50, 130}); return true; }
        if (xbox.raw().xboxNotif.btnStart)  { servo.homeAsync({116, 53, 50, 130}); return true; }
        if (xbox.raw().xboxNotif.btnSelect){ servo.homeAsync({74, 145, 48, 130}); return true; }

        const int STEP = 2;
        if (xbox.raw().xboxNotif.trigRT > 512)     { s0 = constrain(s0+STEP, 36, 126); s1 = constrain(s1-STEP, 0, 150); update = true; }
        if (xbox.raw().xboxNotif.btnRB)             { s0 = constrain(s0-STEP, 36, 126); s1 = constrain(s1+STEP, 0, 150); update = true; }
        if (xbox.raw().xboxNotif.btnA)              { s3 = constrain(s3+STEP, 83, 135); update = true; }
        if (xbox.raw().xboxNotif.btnB)              { s3 = constrain(s3-STEP, 83, 135); update = true; }
        if (xbox.raw().xboxNotif.btnX)              { s2 = constrain(s2+STEP, 0, 180);  update = true; }
        if (xbox.raw().xboxNotif.btnY)              { s2 = constrain(s2-STEP, 0, 180);  update = true; }
        if (xbox.raw().xboxNotif.btnDirUp)          { s1 = constrain(s1-STEP, 0, 150);  update = true; }
        if (xbox.raw().xboxNotif.btnDirDown)        { s1 = constrain(s1+STEP, 0, 150);  update = true; }
        if (xbox.raw().xboxNotif.btnDirLeft)        { s0 = constrain(s0+STEP, 36, 126); update = true; }
        if (xbox.raw().xboxNotif.btnDirRight)       { s0 = constrain(s0-STEP, 36, 126); update = true; }

        if (update) {
            servo.setAngle(0, s0); servo.setAngle(1, s1);
            servo.setAngle(2, s2); servo.setAngle(3, s3);
        }
        return update;
    }
private:
    uint32_t _lastUpdate = 0;
};

// ============================================================================
// Global objects
// ============================================================================
MotorDriver motor;
ServoController servo;
MPUManager mpu;
StepperDriver stepper;
BatteryMonitor battery;
XboxInput xbox;
ChassisController chassis;
RelayControl relay;
ServoButtonHandler servoButtons;

// ============================================================================
// Setup
// ============================================================================
void setup() {
    Serial.begin(115200);
    delay(2000);
    Wire.begin(I2C_SDA, I2C_SCL);
    Wire.setClock(100000);

    motor.begin();
    servo.begin();
    stepper.begin();
    relay.begin();

    if (!mpu.begin()) Serial.println("MPU6050 init failed");

    xbox.begin();
    Serial.println("System init complete");
}

// ============================================================================
// Main loop — 20ms control throttle
// ============================================================================
void loop() {
    uint32_t now = millis();
    xbox.update();
    relay.update();

    if (!xbox.isConnected()) {
        motor.stop();
        return;
    }

    // Home button triggers relay reset
    static bool prevHome = false;
    bool curHome = xbox.raw().xboxNotif.btnXbox;
    if (curHome && !prevHome) relay.triggerReset();
    prevHome = curHome;

    // Process input every loop for responsive button handling
    xbox.process();

    // Stepper motor — no throttle, runs every loop
    int16_t lift = xbox.getLift();
    if (xbox.isLiftActive()) stepper.setSpeed(lift);
    else stepper.stop();
    stepper.update();

    // Servo button handling (40ms throttle inside)
    servoButtons.handle(xbox, servo, now);
    servo.heartbeat(now);
    servo.update(now);

    // Main control logic runs at 20ms intervals
    static uint32_t lastControlUpdate = 0;
    if (now - lastControlUpdate >= 20) {
        lastControlUpdate = now;

        // Sensors & battery (battery has internal 2s throttle)
        float tilt = mpu.isInitialized() ? mpu.updateAndGetTilt() : 0;
        battery.update(motor);

        // Read left stick (lx=forward/back, ly=strafe)
        int16_t ly, lx;
        xbox.getLeftStick(lx, ly);    // lx=forward/back, ly=strafe
        int16_t rot = xbox.getRotation();

        // Parking check (includes lift axis)
        bool forcePark = ChassisController::shouldPark(ly, lx, rot, lift, tilt);

        // Mecanum kinematics solve
        if (forcePark) { ly = lx = rot = 0; }
        chassis.compute(ly, lx, rot, forcePark);

        // Output PWM to motors
        int16_t pwm[4];
        chassis.getPWM(pwm);
        if (battery.status == BatteryMonitor::BAT_CRITICAL)
            motor.stop();
        else
            motor.setPWM(pwm);

        // Debug output every 500ms
        static uint32_t lastPrint = 0;
        if (millis() - lastPrint > 500) {
            Serial.printf("Mode:%d Park:%d Tilt:%.1f V:%.2f | Joy:%d,%d Rot:%d Lift:%d | Servo:%d,%d,%d,%d | Relay:%d\n",
                chassis.mode(), forcePark, tilt, battery.voltage,
                ly, lx, rot, lift,
                servo.angle(0), servo.angle(1), servo.angle(2), servo.angle(3),
                relay.state());
            lastPrint = millis();
        }
    }
}
